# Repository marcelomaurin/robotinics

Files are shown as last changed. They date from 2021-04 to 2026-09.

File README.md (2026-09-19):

# Robotinics

[Português](README.md) · [English](README_EN.md) · [Español](README_ES.md)

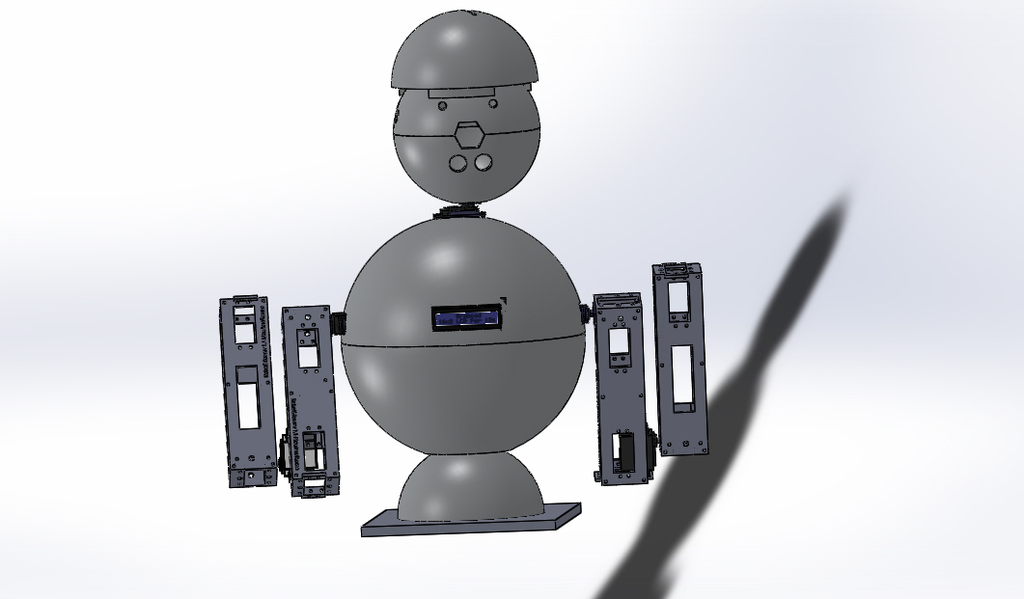
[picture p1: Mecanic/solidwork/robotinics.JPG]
Robotinics


Robotinics é uma plataforma aberta de robótica, automação e experimentação criada para integrar **mecânica, eletrônica, firmware, computação embarcada e software** em um mesmo projeto.

O objetivo não é oferecer apenas um robô pronto, mas uma base evolutiva para estudo, prototipagem e desenvolvimento de novas funcionalidades.

## Origem do projeto

O Robotinics nasceu em **2015** como **Trabalho de Conclusão de Curso (TCC)** do curso de **Técnico em Mecânica Industrial**, apresentado na **Etec José Martimiano da Silva**, em Ribeirão Preto/SP, unidade do **Centro Paula Souza**.

Esse contexto explica a natureza multidisciplinar do projeto desde sua origem: o trabalho não foi concebido apenas como software ou eletrônica, mas como um sistema integrado envolvendo **mecânica, fabricação de peças, eletrônica, acionamentos, sensores, microcontroladores e software**.

A partir do trabalho acadêmico original, o Robotinics continuou evoluindo como plataforma experimental, incorporando novas revisões mecânicas, placas eletrônicas, Arduino, Raspberry Pi, visão computacional e outros módulos de software.

Instituição: [Etec José Martimiano da Silva – Centro Paula Souza](https://www.cps.sp.gov.br/etecs/etec-jose-martimiano-da-silva/)

## Visão geral

O projeto reúne:

- estrutura mecânica e peças para fabricação e impressão 3D;
- projetos de placas eletrônicas e distribuição de alimentação;
- Arduino Mega como controlador principal de baixo nível;
- módulo de cabeça baseado em Arduino Nano;
- sensores, servomotores, motores, laser apontador e ultrassom;
- integração com Raspberry Pi;
- banco de dados e interface web;
- documentação didática e material histórico do projeto.

## Arquitetura

```text
                      Raspberry Pi
                 visão / software / lógica
                           │
                           │ serial
                           ▼
                     Arduino Mega
                controle físico principal
                  /        │         \
             motores    sensores    servos
                           │
                           ▼
                    MCabeca / Nano
                ┌──────────┼──────────┐
              Servo X    Servo Y    Ultrassom
                           │
                       Laser / LEDs
```

O Raspberry Pi fica responsável por processamento de mais alto nível. O Arduino Mega concentra a maior quantidade de I/O e executa o controle físico. O MCabeca é um módulo especializado da cabeça robótica.

## Módulos

| Módulo | Conteúdo |
|---|---|
| [Eletrônica](Eletronic/README.md) | esquemas, placas, alimentação e PCBs |
| [Mecânica](Mecanic/README.md) | SolidWorks, STL e peças estruturais |
| [Software](Software/README.md) | firmware, Raspberry, banco e interface |
| [Arduino](Software/arduino/README.md) | firmwares embarcados |
| [Mega](Software/arduino/robotinics/README.md) | controlador principal do robô |
| [MCabeca](Software/arduino/MCabeca/README.md) | cabeça ativa: servos, laser, LEDs e ultrassom |
| [Raspberry](Software/raspberry/README.md) | processamento de alto nível e I/O |
| [Robotinics AI](docs/ai/README.md) | TCHATGPT, internet, RAG, visão, agentes e documentação assistida |
| [Imagem Yocto](Software/raspberry/yocto/README.md) | Linux reproduzível para Raspberry Pi 4/5 |
| [Database](Software/database/README.md) | estrutura de dados do projeto |
| [Site](Software/site/README.md) | interface web histórica |
| [Documentação](docs/README.md) | manuais e material de referência |

## MCabeca e percepção ativa

O MCabeca possui dois servos associados a um **apontador laser**, LEDs e sensor ultrassônico. A intenção do módulo não é atuar como arma: o laser funciona como referência óptica e apontador visual.

Associado a uma câmera controlada pelo Raspberry Pi, o módulo pode ser usado para:

- apontamento visual;
- varredura angular;
- identificação do ponto laser na imagem;
- auxílio à estimativa de profundidade de uma câmera monocular;
- scanning de uma região;
- combinação de distância visual e ultrassônica;
- acompanhamento experimental de objetos.

A calibração visual pertence ao Raspberry Pi. O microcontrolador deve apenas receber e executar ângulos e comandos físicos.

## Continuação com IA no Raspberry Pi

A continuidade da Rev. 3 propõe o Raspberry Pi como **computador de bordo inteligente**, usando a biblioteca [TCHATGPT](https://github.com/marcelomaurin/CHATGPT) para integrar LLM, agentes, RAG, visão, voz e acesso controlado à internet.

A arquitetura preserva o princípio de segurança do projeto: a IA interpreta, pesquisa e planeja; o Arduino Mega continua responsável pelo controle físico determinístico.

Documentação: [docs/ai/README.md](docs/ai/README.md)

Para agentes de IA que precisem compreender ou atualizar este repositório, consulte também [AGENTS.md](AGENTS.md) e [AI_README.md](AI_README.md).

## Imagem Linux do Raspberry Pi

A continuidade do projeto possui uma camada Yocto própria em [Software/raspberry/yocto/README.md](Software/raspberry/yocto/README.md). Ela cria uma imagem reproduzível para Raspberry Pi 4/5 com gateway serial, rede, voz/visão opcionais e preparação para o runtime TCHATGPT ARM64.

## Firmware

O projeto possui dois firmwares principais:

### Arduino Mega

Local: [Software/arduino/robotinics](Software/arduino/robotinics)

Responsável por controle do robô, motores, servos, sensores, comunicação e segurança básica.

### Arduino Nano — MCabeca

Local: [Software/arduino/MCabeca](Software/arduino/MCabeca)

Responsável pelo módulo de cabeça robótica.

Os firmwares estão passando por uma modernização mantendo compatibilidade com o hardware e o protocolo legado:

- PR #3 — refatoração do firmware do Mega;
- PR #4 — otimização do MCabeca para Arduino Nano.

## Estrutura do repositório

```text
robotinics/
├── Eletronic/
│   ├── arduino/
│   ├── eagle/
│   ├── pcb/
│   └── pcb wizzard/
├── Mecanic/
│   ├── solidwork/
│   └── stl/
├── Software/
│   ├── arduino/
│   │   ├── robotinics/
│   │   └── MCabeca/
│   ├── database/
│   ├── raspberry/
│   │   └── yocto/
│   └── site/
└── docs/
```

## Robotinics Rev. 4

A evolução atual do projeto está organizada na [Robotinics Rev. 4](docs/rev4/README.md), que formaliza a arquitetura em camadas, o roadmap de modernização, a preservação do protocolo legado e os critérios de validação para firmware, Gateway, simulador, IA e distribuição.

A Rev. 4 é incremental: o hardware atual continua sendo a base do projeto e cada mudança estrutural deve ser validada antes de substituir comportamento existente.

## Documentação histórica

O repositório mantém o material completo produzido ao longo da evolução do projeto, inclusive o manual **Projetos IoT com Arduino e Raspberry**.

Consulte [docs/README.md](docs/README.md).

## Filosofia do projeto

Robotinics foi concebido como uma plataforma multidisciplinar. A evolução do projeto deve preservar quatro princípios:

1. hardware reproduzível;
2. módulos independentes;
3. protocolo compatível entre dispositivos;
4. separação entre controle físico e processamento de alto nível.

## Autor

**Marcelo Maurin Martins**

- GitHub: [marcelomaurin](https://github.com/marcelomaurin)
- Site: [Maurinsoft](https://maurinsoft.com.br)

---

Robotinics é um projeto experimental e educacional. Ao trabalhar com motores, alimentação elétrica, laser, baterias ou partes móveis, utilize procedimentos adequados de segurança.

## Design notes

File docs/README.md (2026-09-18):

# Documentação do Robotinics

[Projeto principal](../README.md) · [English](README.en.md) · [Español](README.es.md)

Esta pasta reúne documentação histórica e material didático relacionado ao Robotinics.

## Histórico e origem

O Robotinics foi apresentado originalmente em **2015** como **Trabalho de Conclusão de Curso (TCC)** do curso de **Técnico em Mecânica Industrial** da **Etec José Martimiano da Silva**, em Ribeirão Preto/SP, unidade do **Centro Paula Souza**.

O projeto surgiu com uma proposta multidisciplinar, reunindo mecânica, estrutura física, eletrônica, sensores, acionamentos, microcontroladores e software. O repositório atual preserva materiais de diferentes fases dessa evolução, incluindo arquivos mecânicos, placas, códigos, documentação didática e versões posteriores do sistema.

Instituição: [Etec José Martimiano da Silva – Centro Paula Souza](https://www.cps.sp.gov.br/etecs/etec-jose-martimiano-da-silva/)

## Documentação principal

A referência mais recente do projeto é a **Robotinics Rev. 3**, disponível em [rev3/README.md](rev3/README.md), com edições em português e inglês, manuscritos-fonte e arquivos de reconstrução.

A Rev. 3 consolida a arquitetura moderna do Robotinics, incluindo Raspberry Pi, TCHATGPT, agentes, visão, voz, RAG e controle supervisionado.

## Continuação de IA

A evolução posterior da arquitetura de IA está documentada em [ai/README.md](ai/README.md).

Essa documentação descreve a integração com internet, o runtime no Raspberry Pi e um agente específico para manter os READMEs sincronizados com o código.

## Material histórico

O repositório também preserva **Projetos IoT com Arduino e Raspberry** como documentação histórica.

Esse conteúdo registra conceitos, montagens, experimentos e etapas associadas ao desenvolvimento do projeto.

## Papel desta pasta

O objetivo de `docs/` é concentrar material que não pertence diretamente ao código-fonte ou aos arquivos de fabricação.

Exemplos de conteúdo adequado:

- manual de montagem;
- arquitetura;
- protocolo;
- pinagem;
- tutoriais;
- diagramas;
- histórico;
- imagens técnicas;
- procedimentos de teste.

## Organização futura sugerida

```text
docs/
├── architecture/
├── assembly/
├── electronics/
├── firmware/
├── protocol/
├── raspberry/
├── vision/
└── history/
```

## Documentação modular

A documentação atual está sendo distribuída também em READMEs próximos aos respectivos módulos.

Isso facilita a navegação:

- eletrônica documentada em `Eletronic/`;
- mecânica em `Mecanic/`;
- software em `Software/`;
- Mega e MCabeca em suas próprias pastas.

A pasta `docs/` deve concentrar materiais mais extensos e transversais ao projeto.

## Idiomas

A documentação principal utiliza:

- Português;
- English;
- Español.

A versão em português é usada como referência principal quando não houver outra indicação.

## Pinout dos controladores

A documentação de pinout dos controladores está em [hardware/pinout/README.md](hardware/pinout/README.md), cobrindo Arduino Mega/ATmega2560, MCabeca/ATmega328P e Raspberry Pi 4/5.

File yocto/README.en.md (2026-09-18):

# Robotinics Yocto Image

[Português](README.md) · [Español](README.es.md)

This directory defines the reproducible Robotinics Raspberry Pi image using Yocto Project 6.0 Wrynose LTS, meta-raspberrypi and the custom meta-robotinics layer.

Default machine is raspberrypi4-64, with raspberrypi5 also supported by the manifests.

Build:

    cd yocto
    ./scripts/build.sh rpi4

The image includes networking, SSH, Python, serial gateway support, optional vision and speech features, and the filesystem/configuration foundation for the TCHATGPT ARM64 runtime.

The TCHATGPT source recipe is pinned for reproducibility but is not installed by default until ARM64 compilation is validated.

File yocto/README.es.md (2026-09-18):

# Imagen Yocto de Robotinics

[Português](README.md) · [English](README.en.md)

Esta carpeta define la imagen reproducible para Raspberry Pi usando Yocto Project 6.0 Wrynose LTS, meta-raspberrypi y la capa meta-robotinics.

La máquina predeterminada es raspberrypi4-64 y también existe un manifiesto para raspberrypi5.

Build:

    cd yocto
    ./scripts/build.sh rpi4

La imagen incluye red, SSH, Python, gateway serie, funciones opcionales de visión y voz, y la base para el runtime TCHATGPT ARM64.

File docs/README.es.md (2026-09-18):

# Documentación de Robotinics

[Proyecto principal](../README_ES.md) · [Português](README.md) · [English](README.en.md)

Esta carpeta contiene documentación histórica y material educativo.

## Historia y origen

Robotinics fue presentado originalmente en **2015** como **Trabajo de Conclusión de Curso (TCC)** del curso de **Técnico en Mecánica Industrial** de la **Etec José Martimiano da Silva**, en Ribeirão Preto, São Paulo, Brasil, unidad del **Centro Paula Souza**.

El proyecto tuvo un carácter multidisciplinario desde su origen, integrando mecánica, estructura física, electrónica, sensores, accionamientos, microcontroladores y software. El repositorio actual conserva materiales de diferentes etapas de esa evolución.

Institución: [Etec José Martimiano da Silva – Centro Paula Souza](https://www.cps.sp.gov.br/etecs/etec-jose-martimiano-da-silva/)

Uno de los principales recursos es el material **Proyectos IoT con Arduino y Raspberry**.

La documentación específica se mantiene cerca de cada módulo. `docs/` debe concentrar arquitectura, montaje, protocolos, diagramas, tutoriales e historia del proyecto.

Los idiomas principales son portugués, inglés y español.

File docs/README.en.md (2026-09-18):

# Robotinics Documentation

[Main project](../README_EN.md) · [Português](README.md) · [Español](README.es.md)

This folder contains historical documentation and educational material related to Robotinics.

## History and origin

Robotinics was originally presented in **2015** as a **final course project (TCC)** for the **Industrial Mechanics Technical Program** at **Etec José Martimiano da Silva**, Ribeirão Preto, São Paulo, Brazil, part of **Centro Paula Souza**.

The project was multidisciplinary from the start, combining mechanics, physical structure, electronics, sensors, actuators, microcontrollers and software. The current repository preserves material from different stages of that evolution.

Institution: [Etec José Martimiano da Silva – Centro Paula Souza](https://www.cps.sp.gov.br/etecs/etec-jose-martimiano-da-silva/)

A major resource is the **IoT Projects with Arduino and Raspberry** material stored in the repository.

Module-specific documentation is kept near each subsystem, while `docs/` should contain broader material such as architecture, assembly guides, protocol specifications, diagrams, tutorials and project history.

Primary documentation languages are Portuguese, English and Spanish.

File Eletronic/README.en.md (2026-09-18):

# Robotinics Electronics

[Main project](../README_EN.md) · [Português](README.md) · [Español](README.es.md)

This directory contains the electronic layer of Robotinics. It connects the embedded controllers to motors, servos, sensors, LEDs, auxiliary modules and power circuitry.

## Purpose

The electronics were designed to keep the robot modifiable and repairable without depending on one proprietary board. The repository contains several generations of circuit files, serving both as fabrication references and as a historical record of the project.

## Structure

### `arduino/`

Pinout notes and controller connection references.

### `eagle/`

Autodesk EAGLE projects, including:

- servo controller board;
- LED board;
- charger circuit;
- 5 V distribution board.

### `pcb/`

PCB layouts, fabrication mirrors and images from multiple revisions.

### `pcb wizzard/`

Historical PCB Wizard files.

## Software integration

Electronic pin assignments must match the embedded firmware:

- Arduino Mega: main physical controller;
- Arduino Nano / MCabeca: specialized head module.

Any pinout change should be reflected in hardware, firmware and documentation at the same time.

## Power

Motors and servos can require substantially more current than Arduino regulators can safely provide. When reproducing the hardware:

- size the power supply correctly;
- use common ground where required;
- avoid powering multiple servos from the Arduino regulator;
- provide appropriate protection and distribution;
- verify voltage drop under simultaneous load.

## Repository status

This folder contains historical and current material. Not every file should be treated as production-ready.

The documentation effort should progressively identify the official reference schematic, PCB, BOM and pinout.

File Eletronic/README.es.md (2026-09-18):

# Electrónica de Robotinics

[Proyecto principal](../README_ES.md) · [Português](README.md) · [English](README.en.md)

Este directorio contiene la capa electrónica de Robotinics. Conecta los controladores embebidos con motores, servos, sensores, LEDs, módulos auxiliares y circuitos de alimentación.

## Objetivo

La electrónica fue concebida para permitir que el robot sea modificable y reparable sin depender de una placa propietaria única. El repositorio contiene varias generaciones de archivos, útiles como referencia de fabricación y como registro histórico.

## Estructura

### `arduino/`

Notas de pines y conexiones.

### `eagle/`

Proyectos EAGLE, incluyendo:

- control de servomotores;
- placas de LEDs;
- cargador;
- distribución de 5 V.

### `pcb/`

Diseños PCB, espejos e imágenes de distintas revisiones.

### `pcb wizzard/`

Archivos históricos de PCB Wizard.

## Integración

Los pines deben coincidir con los firmwares:

- Arduino Mega: controlador físico principal;
- Arduino Nano / MCabeca: módulo de cabeza.

Todo cambio de pin debe reflejarse en hardware, firmware y documentación.

## Alimentación

Los motores y servos pueden requerir corrientes elevadas. Se recomienda dimensionar correctamente la fuente, utilizar masa común cuando corresponda, evitar alimentar múltiples servos desde el regulador del Arduino y verificar caída de tensión bajo carga.

## Estado del material

Existen archivos de diferentes generaciones. No todos representan una versión lista para producción.

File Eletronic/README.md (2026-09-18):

# Eletrônica do Robotinics

[Projeto principal](../README.md) · [English](README.en.md) · [Español](README.es.md)

Este diretório concentra a parte eletrônica do Robotinics. Ele representa a camada que conecta os controladores embarcados aos motores, servomotores, sensores, LEDs, módulos auxiliares e circuitos de alimentação.

## Objetivo

A proposta da eletrônica do Robotinics é permitir que o robô seja construído, modificado e reparado sem depender de uma única placa proprietária. O projeto reúne arquivos de diferentes períodos de evolução, servindo tanto como base de fabricação quanto como registro histórico das soluções adotadas.

## Estrutura

### `arduino/`

Contém anotações de pinagem e referências de conexão relacionadas aos microcontroladores.

O arquivo `pinos arduino.txt` registra parte da distribuição física usada no Arduino Mega, incluindo conexões de servos, motores, RF e LCD.

### `eagle/`

Contém projetos criados no Autodesk EAGLE.

Entre os circuitos existentes estão:

- placa controladora de servomotor;
- placa de LEDs;
- circuito do carregador;
- placa de distribuição de 5 V.

Esses arquivos devem ser tratados como projetos de hardware sujeitos a revisão. Antes de fabricar uma placa, confirme esquemático, alimentação, versão dos componentes e correspondência com o firmware utilizado.

### `pcb/`

Contém arquivos de placa, espelhos de fabricação e imagens de diferentes revisões.

Há materiais para:

- controle de servomotores;
- controle de LEDs;
- distribuição elétrica;
- fonte;
- versões intermediárias e históricas das placas.

### `pcb wizzard/`

Contém arquivos produzidos em versões anteriores do projeto usando PCB Wizard.

## Integração com o software

A eletrônica deve acompanhar a pinagem dos firmwares:

- Arduino Mega: controlador físico principal;
- Arduino Nano / MCabeca: módulo especializado da cabeça.

Alterações de pinagem devem ser refletidas simultaneamente no hardware, no firmware e na documentação.

## Alimentação

Motores e servos podem exigir correntes significativamente maiores do que as fornecidas diretamente pelos reguladores dos microcontroladores.

Ao reproduzir ou modificar o circuito:

- dimensione corretamente a fonte;
- mantenha terra comum entre os módulos quando necessário;
- evite alimentar vários servos diretamente pelo regulador do Arduino;
- utilize proteção e distribuição adequadas;
- verifique queda de tensão durante acionamentos simultâneos.

## Situação do conteúdo

O diretório contém material de diferentes gerações do Robotinics. Nem todo arquivo representa a revisão mais recente ou uma placa pronta para produção.

O objetivo da modernização da documentação é permitir identificar progressivamente:

1. arquivos históricos;
2. versão de referência;
3. esquemático atual;
4. PCB atual;
5. lista de materiais;
6. pinagem oficial.

## Segurança

Antes de energizar qualquer circuito, confirme polaridade, tensão nominal, corrente e isolamento. Motores, baterias e servos podem provocar aquecimento, curto-circuito ou movimento inesperado quando ligados incorretamente.

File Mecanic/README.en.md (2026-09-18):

# Robotinics Mechanics

[Main project](../README_EN.md) · [Português](README.md) · [Español](README.es.md)

The `Mecanic` directory contains the physical Robotinics structure: CAD models, assemblies and parts for 3D printing.

## Purpose

Mechanical design is part of the system architecture. Robotinics was built so software, electronics and physical structure can evolve together.

## Structure

### `solidwork/`

SolidWorks parts and assemblies, including body sections, bases, arms, head parts, laser support and Raspberry Pi support.

### `stl/`

Exported files for fabrication and 3D printing.

## Head module

The mechanical head supports two servo axes, the laser pointer and the ultrasonic sensor. It can work together with a camera handled by the Raspberry Pi.

The laser is an optical/visual reference used in active-perception and scanning experiments.

## Revisions

Several historical revisions coexist. Before printing, verify scale, mounting points, servo compatibility and the intended assembly revision.

A future reference release should provide a complete mechanical BOM, printing orientation, material recommendations and assembly sequence.

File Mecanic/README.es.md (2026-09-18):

# Mecánica de Robotinics

[Proyecto principal](../README_ES.md) · [Português](README.md) · [English](README.en.md)

La carpeta `Mecanic` contiene la estructura física de Robotinics: modelos CAD, ensamblajes y piezas para impresión 3D.

## Estructura

### `solidwork/`

Piezas y ensamblajes SolidWorks.

### `stl/`

Archivos exportados para fabricación e impresión 3D.

## Módulo de cabeza

La cabeza soporta dos ejes con servos, el puntero láser y el sensor ultrasónico. Puede trabajar junto con una cámara procesada por Raspberry Pi.

El láser funciona como referencia visual/óptica para experimentos de percepción activa.

## Revisiones

Coexisten varias revisiones históricas. Antes de imprimir una pieza, verifique escala, fijaciones, compatibilidad con servos y versión de montaje.

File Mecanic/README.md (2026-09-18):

# Mecânica do Robotinics

[Projeto principal](../README.md) · [English](README.en.md) · [Español](README.es.md)

A pasta `Mecanic` reúne a estrutura física do Robotinics: modelos CAD, montagens e peças destinadas à impressão 3D.

## Objetivo

A mecânica faz parte da arquitetura do projeto. O Robotinics foi concebido para que software, eletrônica e estrutura física possam evoluir em conjunto.

O repositório não contém apenas uma carcaça: ele inclui peças funcionais relacionadas a braços, corpo, cabeça, suportes e integração dos componentes eletrônicos.

## Estrutura

### `solidwork/`

Contém arquivos de peças e montagens em SolidWorks.

Entre os arquivos existentes estão:

- montagem completa do Robotinics;
- corpo;
- bases;
- braços;
- suporte do laser;
- suporte do Raspberry Pi;
- peças de cabeça;
- extensões e suportes auxiliares.

Também existem imagens de referência da montagem.

### `stl/`

Contém arquivos exportados para impressão 3D.

Entre as peças disponíveis estão:

- base do braço;
- extensão do braço;
- corpo inferior e superior;
- placa da cabeça;
- partes inferior e superior da cabeça;
- prolongadores;
- suporte do laser;
- suporte do Raspberry Pi.

## Cabeça e laser

A estrutura da cabeça foi projetada para acomodar o módulo MCabeca.

O conjunto possui:

- dois eixos de movimento por servo;
- suporte para apontador laser;
- integração com sensor ultrassônico;
- possibilidade de trabalhar junto a uma câmera.

O apontador laser é utilizado como referência visual/óptica. Associado à câmera e ao processamento no Raspberry Pi, pode apoiar experimentos de scanning e percepção ativa.

## Revisões

O diretório contém peças de diferentes revisões.

Antes de imprimir:

1. confirme o nome e a revisão da peça;
2. valide a escala do STL;
3. verifique pontos de fixação;
4. confirme compatibilidade com servos e placas instalados;
5. confira a montagem completa antes de fabricar várias unidades.

## Próxima evolução documental

Uma revisão futura deve identificar claramente:

- conjunto mecânico de referência;
- lista completa das peças;
- quantidade necessária de cada peça;
- orientação de impressão;
- material recomendado;
- parafusos e elementos de fixação;
- sequência de montagem.

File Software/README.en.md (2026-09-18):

# Robotinics Software

[Main project](../README_EN.md) · [Português](README.md) · [Español](README.es.md)

This directory contains the software layers of Robotinics.

## Architecture

```text
Raspberry Pi
  processing / integration / vision
                │
                ▼
          Arduino Mega
       main physical controller
          │           │
          │           └── MCabeca / Arduino Nano
          │
          ├── motors
          ├── servos
          └── sensors
```

## Modules

- [Arduino](arduino/README.md): embedded firmware;
- [Raspberry](raspberry/README.md): high-level processing and integration;
- [Database](database/README.md): project data structures;
- [Site](site/README.md): historical web interface.

## Design principle

Microcontrollers should remain deterministic and hardware-focused. Vision, camera calibration, triangulation, mission logic and AI belong to the Raspberry Pi or another high-level computer.

Protocol compatibility between devices is considered part of the Robotinics system contract.

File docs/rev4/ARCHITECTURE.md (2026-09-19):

# Arquitetura Robotinics Rev. 4

## Visão geral

A Rev. 4 formaliza a separação entre hardware, controle determinístico e processamento de alto nível.

```text
Usuário / Control Center / serviços
              |
              v
       Robotinics AI Runtime
      tarefas / RAG / visão / voz
              |
              v
       Robotinics Gateway
   validação / fila / estado / API
              |
              v
         Arduino Mega
        Body Controller
       /      |       \
 motores   sensores   servos
              |
              +-------------------+
                                  |
                                  v
                         Arduino Nano
                         Head Controller
                      pan / tilt / laser
                       LEDs / ultrassom
```

## Nível 0 — Hardware

Inclui atuadores, sensores, drivers, alimentação, estrutura mecânica, placas e cabeamento.

Responsabilidades:
- executar o efeito físico;
- oferecer sinais elétricos aos controladores;
- respeitar limites mecânicos e elétricos definidos pelo projeto.

## Nível 1 — Controle determinístico

### Body Controller — Arduino Mega

Responsabilidades:
- motores de locomoção;
- servos do corpo;
- sensores diretamente conectados;
- comandos Device;
- intertravamentos simples;
- parada segura;
- comunicação com o computador de bordo;
- encaminhamento de comandos para módulos subordinados quando necessário.

Não é responsabilidade do Mega:
- interpretação de linguagem natural;
- acesso à internet;
- planejamento por LLM;
- visão computacional de alto nível.

### Head Controller — Arduino Nano / MCabeca

Responsabilidades:
- pan/tilt;
- laser apontador;
- LEDs;
- olhos;
- ultrassom;
- varreduras físicas locais.

O Raspberry é responsável por calibração visual e interpretação de imagem.

## Nível 2 — Cognitive Controller — Raspberry Pi

### Gateway

Único serviço autorizado a conversar diretamente com o Body Controller pela serial principal.

Responsabilidades:
- abrir e manter a conexão;
- serializar comandos;
- aplicar catálogo/validação;
- timeout;
- request id;
- parser de respostas;
- estado atual;
- histórico;
- eventos;
- health check.

### AI Runtime

Responsabilidades:
- receber perguntas;
- criar tarefas;
- consultar telemetria;
- consultar documentação;
- RAG;
- visão;
- voz;
- internet controlada;
- produzir diagnóstico e propostas de ação.

A saída do LLM não é autorização para hardware.

## Fluxo de ação física

```text
pedido do usuário
      |
      v
interpretação
      |
      v
plano / proposta
      |
      v
política e validação
      |
      v
confirmação quando necessária
      |
      v
Gateway
      |
      v
Body/Head Controller
      |
      v
hardware
      |
      v
telemetria observada
```

## Estado e telemetria

O estado deve distinguir:

- estado solicitado;
- estado confirmado pelo controlador;
- telemetria observada;
- inferência da IA.

Nunca tratar intenção de comando como comprovação de execução.

## Segurança

A segurança física deve existir abaixo da camada de IA.

Requisitos de arquitetura:
- parada prioritária;
- timeout de movimento;
- watchdog;
- limites de servo;
- rejeição de comandos desconhecidos;
- modo degradado quando o Raspberry falhar;
- ausência de execução direta de conteúdo vindo da internet.

## Interfaces futuras

A arquitetura deve permitir, sem obrigar a substituição do hardware atual:

- outros controladores;
- novos módulos de sensores;
- câmeras;
- microfones;
- alto-falantes;
- novos transportes além da serial;
- clientes web, desktop ou mobile.

A descoberta de capacidades deve reduzir dependência de configuração rígida, mas sem remover suporte ao protocolo legado.

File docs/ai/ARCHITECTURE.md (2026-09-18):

# Arquitetura de IA do Robotinics

## Princípio

A IA é uma camada cognitiva, não uma camada elétrica. Ela pode interpretar intenção, buscar informação, montar planos e explicar resultados. O firmware continua responsável pelo comportamento determinístico.

## Camadas

### 1. Hardware

Motores, sensores, servos, laser, LEDs e alimentação.

### 2. Controle determinístico

Arduino Mega e MCabeca.

Responsabilidades:

- comandos físicos;
- limites;
- timeouts;
- estados;
- intertravamentos;
- leituras.

### 3. Robot Gateway

Executado no Raspberry.

Responsável por:

- serial;
- catálogo de comandos;
- normalização de telemetria;
- timeout;
- heartbeat;
- request_id;
- log de execução.

### 4. Serviços

- câmera;
- voz;
- RAG;
- internet;
- banco;
- arquivos;
- telemetria.

### 5. TCHATGPT

- LLM;
- agente;
- planejamento;
- seleção de ferramenta;
- explicação;
- contexto.

## Internet como ferramenta

A internet é uma ferramenta do agente, equivalente a câmera ou RAG.

O LLM não recebe acesso irrestrito ao sistema operacional.

A ferramenta de internet recebe uma solicitação estruturada e retorna fontes, data de consulta, título e resumo.

## Estado central

O Raspberry deve manter um `RobotState` independente da conversa:

```text
connection
mode
armed
battery
motors
servos
distances
head_position
laser
leds
last_telemetry
faults
current_task
```

## Tarefas

Toda pergunta pode gerar uma tarefa lógica:

```text
Task
├── understand
├── collect_context
├── collect_telemetry
├── search_rag
├── search_internet
├── reason
└── answer
```

Ações físicas acrescentam:

```text
├── build_action_plan
├── validate
├── request_confirmation
├── execute
└── verify_telemetry
```

## Segurança

O validador deve rejeitar:

- comando não catalogado;
- parâmetro fora de faixa;
- movimento em estado não armado;
- telemetria antiga;
- ação baseada apenas em conteúdo web;
- cadeia ilimitada de ações;
- repetição automática após falha;
- ação física baseada apenas em memória de conversa.

## Operação sem internet

O robô deve continuar controlável sem internet e sem LLM.

Sem internet:

- RAG local continua disponível;
- telemetria continua disponível;
- controle manual continua disponível;
- segurança continua funcionando.

Sem LLM:

- gateway e firmware continuam operacionais.

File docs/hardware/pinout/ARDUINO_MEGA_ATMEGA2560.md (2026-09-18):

# Arduino Mega 2560 / ATmega2560 — Pinout Robotinics

[Índice](README.md) · [Firmware](../../../Software/arduino/robotinics/README.md)

O Arduino Mega 2560 é o controlador físico principal do Robotinics.

## Interfaces principais

| Recurso | Pinos Arduino Mega | Porta ATmega2560 | Uso Robotinics |
|---|---|---|---|
| Serial0 | D0 RX / D1 TX | PE0 / PE1 | USB/console, 115200 bps |
| Serial1 | D19 RX1 / D18 TX1 | PD2 / PD3 | Bluetooth, 9600 bps |
| Serial2 | D17 RX2 / D16 TX2 | PH0 / PH1 | reservado/associado historicamente a RF |
| Serial3 | D15 RX3 / D14 TX3 | PJ0 / PJ1 | GPS, 4800 bps |
| I²C | D20 SDA / D21 SCL | PD1 / PD0 | LCD I²C, endereço 0x20 |
| SPI | D50–D53 | PB3/PB2/PB1/PB0 | disponível; sem uso principal confirmado |

## Servomotores

| Função Robotinics | Pino Mega | ATmega2560 | Recurso |
|---|---:|---|---|
| Cabeça principal | D6 | PH3 | PWM |
| Braço direito | D44 | PL5 | PWM |
| Movimento/punho direito | D8 | PH5 | PWM |
| Braço esquerdo | D9 | PH6 | PWM |
| Garra esquerda | D10 | PB4 | PWM |
| Garra direita | D11 | PB5 | PWM |
| Punho esquerdo | D46 | PL3 | PWM |

Observação: a biblioteca `Servo` usa temporizadores internos e não depende exclusivamente do PWM de hardware do pino.

## Ponte H / tração

| Sinal | Pino Mega | ATmega2560 | Função |
|---|---:|---|---|
| ENA | D26 | PA4 | habilitação motor A |
| IN1 | D28 | PA6 | direção motor A |
| IN2 | D30 | PC7 | direção motor A |
| IN3 | D34 | PC3 | direção motor B |
| IN4 | D32 | PC5 | direção motor B |
| ENB | D36 | PC1 | habilitação motor B |

## Ultrassônicos

| Sensor | Trigger | MCU Trigger | Echo | MCU Echo |
|---|---:|---|---:|---|
| Ré | D2 | PE4 | D3 | PE5 |
| Frente | D40 | PG1 | D35 | PC2 |
| Cabeça/corpo | D41 | PG0 | D42 | PL7 |

## Entradas analógicas

| Função | Arduino | ATmega2560 |
|---|---|---|
| Corrente | A0 | PF0 / ADC0 |
| Acelerômetro X | A1 | PF1 / ADC1 |
| Acelerômetro Y | A2 | PF2 / ADC2 |
| Acelerômetro Z | A3 | PF3 / ADC3 |
| Sensor de gás | A4 | PF4 / ADC4 |
| Canal adicional gás | A5 | PF5 / ADC5 |
| Tensão | A6 | PF6 / ADC6 |

## Comunicação com controlador secundário

O firmware declara `SoftwareSerial mySerial(Arduino2TX, Arduino2RX)` com `Arduino2TX=38` e `Arduino2RX=37`. No construtor SoftwareSerial a ordem é receivePin, transmitPin.

| Papel real | Pino Mega | ATmega2560 |
|---|---:|---|
| RX SoftwareSerial | D38 | PD7 |
| TX SoftwareSerial | D37 | PC0 |

Os nomes históricos das constantes estão invertidos em relação à semântica do construtor. Não alterar a fiação apenas pelo nome da constante.

## Rádio frequência

| Sinal | Pino Mega | MCU |
|---|---:|---|
| RF RX | D17 | PH0 / RX2 |
| RF TX | D16 | PH1 / TX2 |

## Pinout digital completo do Mega

| Arduino | ATmega2560 | Arduino | ATmega2560 |
|---:|---|---:|---|
| D0 | PE0 | D27 | PA5 |
| D1 | PE1 | D28 | PA6 |
| D2 | PE4 | D29 | PA7 |
| D3 | PE5 | D30 | PC7 |
| D4 | PG5 | D31 | PC6 |
| D5 | PE3 | D32 | PC5 |
| D6 | PH3 | D33 | PC4 |
| D7 | PH4 | D34 | PC3 |
| D8 | PH5 | D35 | PC2 |
| D9 | PH6 | D36 | PC1 |
| D10 | PB4 | D37 | PC0 |
| D11 | PB5 | D38 | PD7 |
| D12 | PB6 | D39 | PG2 |
| D13 | PB7 | D40 | PG1 |
| D14 | PJ1 | D41 | PG0 |
| D15 | PJ0 | D42 | PL7 |
| D16 | PH1 | D43 | PL6 |
| D17 | PH0 | D44 | PL5 |
| D18 | PD3 | D45 | PL4 |
| D19 | PD2 | D46 | PL3 |
| D20 | PD1 | D47 | PL2 |
| D21 | PD0 | D48 | PL1 |
| D22 | PA0 | D49 | PL0 |
| D23 | PA1 | D50 | PB3 |
| D24 | PA2 | D51 | PB2 |
| D25 | PA3 | D52 | PB1 |
| D26 | PA4 | D53 | PB0 |

## Entradas analógicas completas

| Arduino | MCU | Arduino | MCU |
|---:|---|---:|---|
| A0 | PF0 | A8 | PK0 |
| A1 | PF1 | A9 | PK1 |
| A2 | PF2 | A10 | PK2 |
| A3 | PF3 | A11 | PK3 |
| A4 | PF4 | A12 | PK4 |
| A5 | PF5 | A13 | PK5 |
| A6 | PF6 | A14 | PK6 |
| A7 | PF7 | A15 | PK7 |

## Alimentação

Motores e servos não devem ser alimentados diretamente pelos pinos de I/O do ATmega2560. Documentar separadamente fonte de lógica, fonte de servos, fonte dos motores, reguladores, aterramento comum e proteções.

## Diagrama visual

Pinout funcional do Arduino Mega no Robotinics

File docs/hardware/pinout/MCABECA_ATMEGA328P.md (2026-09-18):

# MCabeca — Arduino Nano / ATmega328P

[Índice](README.md) · [MCabeca](../../../Software/arduino/MCabeca/README.md)

O MCabeca utiliza Arduino Nano / ATmega328P para controlar a cabeça física do Robotinics.

## Pinagem usada

| Função | Nano | ATmega328P | Recurso |
|---|---:|---|---|
| Echo ultrassônico | D2 | PD2 | INT0 |
| Laser | D3 | PD3 | PWM / INT1 |
| LED vermelho | D4 | PD4 | digital |
| LED azul | D6 | PD6 | PWM |
| Olhos | D7 | PD7 | digital |
| Servo X | D8 | PB0 | digital |
| LED verde | D9 | PB1 | PWM |
| Servo Y | D12 | PB4 | digital |
| Trigger ultrassônico | D13 | PB5 | SCK / LED onboard |

## UART

| Função | Nano | ATmega328P |
|---|---:|---|
| RX | D0 | PD0 / RXD |
| TX | D1 | PD1 / TXD |

No firmware histórico atualmente em `master`, a UART é inicializada em 57600 bps. Qualquer alteração de velocidade precisa ser feita nos dois lados da comunicação.

## Servo X/Y

- Servo X → D8 / PB0
- Servo Y → D12 / PB4

O Nano recebe ângulos; calibração de câmera e conversão pixel→ângulo pertencem ao Raspberry Pi.

## Laser

Laser → D3 / PD3. O laser é apontador/referência óptica. Se o módulo exigir corrente acima do permitido pelo I/O, usar transistor/MOSFET adequado.

## LEDs

- Vermelho → D4 / PD4
- Azul → D6 / PD6
- Verde → D9 / PB1
- Olhos → D7 / PD7

## Ultrassom

- Trigger → D13 / PB5
- Echo → D2 / PD2

## Pinout lógico do Nano

| Nano | ATmega328P | Observação |
|---:|---|---|
| D0 | PD0 | RX |
| D1 | PD1 | TX |
| D2 | PD2 | INT0 |
| D3 | PD3 | PWM / INT1 |
| D4 | PD4 | digital |
| D5 | PD5 | PWM |
| D6 | PD6 | PWM |
| D7 | PD7 | digital |
| D8 | PB0 | digital |
| D9 | PB1 | PWM |
| D10 | PB2 | PWM / SS |
| D11 | PB3 | PWM / MOSI |
| D12 | PB4 | MISO |
| D13 | PB5 | SCK |
| A0 | PC0 | ADC0 |
| A1 | PC1 | ADC1 |
| A2 | PC2 | ADC2 |
| A3 | PC3 | ADC3 |
| A4 | PC4 | ADC4 / SDA |
| A5 | PC5 | ADC5 / SCL |
| A6 | ADC6 | somente analógico |
| A7 | ADC7 | somente analógico |

## Alimentação

O Nano e os periféricos devem compartilhar referência de GND. Servos devem ter alimentação dimensionada adequadamente e não devem depender do regulador do Nano.

## Diagrama visual

Pinout funcional do MCabeca / Arduino Nano

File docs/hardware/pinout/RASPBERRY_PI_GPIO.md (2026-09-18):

# Raspberry Pi 4/5 — GPIO de 40 pinos

[Índice](README.md) · [Raspberry Pi](../../../Software/raspberry/README.md)

O Raspberry Pi é o computador de bordo do Robotinics. O SoC Broadcom é BGA; para montagem/manutenção o pinout relevante é o header GPIO de 40 pinos.

## Header

| Physical | Função | Physical | Função |
|---:|---|---:|---|
| 1 | 3.3 V | 2 | 5 V |
| 3 | GPIO2 / SDA1 | 4 | 5 V |
| 5 | GPIO3 / SCL1 | 6 | GND |
| 7 | GPIO4 | 8 | GPIO14 / TXD0 |
| 9 | GND | 10 | GPIO15 / RXD0 |
| 11 | GPIO17 | 12 | GPIO18 / PWM0 |
| 13 | GPIO27 | 14 | GND |
| 15 | GPIO22 | 16 | GPIO23 |
| 17 | 3.3 V | 18 | GPIO24 |
| 19 | GPIO10 / MOSI | 20 | GND |
| 21 | GPIO9 / MISO | 22 | GPIO25 |
| 23 | GPIO11 / SCLK | 24 | GPIO8 / CE0 |
| 25 | GND | 26 | GPIO7 / CE1 |
| 27 | GPIO0 / ID_SD | 28 | GPIO1 / ID_SC |
| 29 | GPIO5 | 30 | GND |
| 31 | GPIO6 | 32 | GPIO12 / PWM0 |
| 33 | GPIO13 / PWM1 | 34 | GND |
| 35 | GPIO19 / PWM1 / PCM_FS | 36 | GPIO16 |
| 37 | GPIO26 | 38 | GPIO20 / PCM_DIN |
| 39 | GND | 40 | GPIO21 / PCM_DOUT |

## Uso atual no Robotinics

A arquitetura moderna prevê Raspberry Pi ↔ Arduino Mega por USB serial: Raspberry USB → `/dev/ttyACM0` → USB/Serial0 do Mega.

Portanto GPIO14/GPIO15 não são necessários para a comunicação principal.

## UART GPIO futura

- Physical 8 = GPIO14 / TXD0
- Physical 10 = GPIO15 / RXD0
- Physical 6 = GND

### Atenção

O Raspberry Pi usa lógica de 3,3 V. O Arduino Mega usa tipicamente 5 V. Nunca conecte diretamente uma saída de 5 V do Mega a um GPIO do Raspberry. Use conversor de nível apropriado.

## I²C

- Physical 3 = GPIO2 / SDA1
- Physical 5 = GPIO3 / SCL1

## SPI

- Physical 19 = GPIO10 / MOSI
- Physical 21 = GPIO9 / MISO
- Physical 23 = GPIO11 / SCLK
- Physical 24 = GPIO8 / CE0
- Physical 26 = GPIO7 / CE1

## Alimentação

Os pinos 5 V e 3,3 V são alimentação, não GPIO. Nunca aplique 5 V em um GPIO BCM.

## Raspberry Pi 4 e 5

Para os sinais GPIO tradicionais documentados aqui, o header físico de 40 pinos mantém compatibilidade. Funções alternativas específicas do SoC devem ser confirmadas antes do uso.

## Diagrama de conexão com o Mega

Raspberry Pi conectado ao Arduino Mega

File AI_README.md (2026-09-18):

# Robotinics — Entrada rápida para IA

Este arquivo fornece contexto rápido a um agente de IA antes de modificar o projeto.

## O que é o Robotinics

Robotinics é uma plataforma robótica multidisciplinar iniciada em 2015 como TCC de Técnico em Mecânica Industrial e posteriormente expandida com Arduino, Raspberry Pi, software, visão e IA.

## Arquitetura

- Raspberry Pi: processamento de alto nível;
- Arduino Mega: controle físico principal;
- Arduino Nano / MCabeca: cabeça robótica;
- TCHATGPT: camada de IA da Rev. 3 e continuidade atual;
- internet: ferramenta consultiva controlada pelo Raspberry;
- RAG: documentação local do próprio projeto.

## Regra principal

**IA sugere, interpreta, pesquisa e planeja. O controle físico é validado e executado por camadas determinísticas.**

## Antes de alterar qualquer coisa

Leia `AGENTS.md`.

Depois leia o README do módulo afetado e, quando relevante, `docs/rev3/`.

## Continuação de IA

A proposta atual está em `docs/ai/` e `Software/raspberry/AI/`.

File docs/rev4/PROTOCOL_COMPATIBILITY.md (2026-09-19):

# Robotinics Device Protocol 1.x

## Status

Esta especificação descreve o protocolo textual compatível com o firmware histórico do Robotinics e suas extensões compatíveis da Rev. 4.

O objetivo é permitir que um cliente implemente integração com o Body Controller sem precisar ler o firmware.

## Transporte

### Body Controller / Arduino Mega

Canal principal atual:

```text
USB Serial
115200 bps
8N1
linha terminada por LF
```

Bluetooth legado:

```text
9600 bps
linha terminada por LF
```

Canal para MCabeca:

```text
9600 bps
```

## Modelo de requisição

Cada comando é enviado como uma única linha:

```text
COMMAND\n
```

O Body Controller pode emitir zero ou mais linhas de resposta e termina o processamento do comando com:

```text
$>
```

O Gateway usa esse prompt como marcador de conclusão da requisição.

## Compatibilidade

Protocol 1.x preserva:

- nomes dos comandos históricos;
- semântica dos comandos;
- formato textual;
- prompt `$>`;
- baud rates existentes;
- namespace `MCAB:`.

Extensões 1.x podem adicionar novos comandos e novas linhas estruturadas, desde que clientes antigos continuem funcionando.

## Categorias de comandos

### Movimento

```text
FRENTE
RE
PARA
GESQ
GDIR
```

`PARA` possui prioridade lógica no parser.

Movimento contínuo é protegido por SafetyController:

- watchdog de controle;
- timeout máximo de ordem;
- parada por obstáculo.

### Sensores

```text
ULTRA
ULTRA1
ULTRA2
ACEL
GAS
CORR
GPS
```

### Servos do corpo

```text
GCABECAESQ=<0..180>
GCABECADIR=<0..180>
GBDIR=<0..180>
GBESQ=<0..180>
GPGARRADIR=<0..180>
GPGARRAESQ=<0..180>
GPPUNHOESQ=<0..180>
GPPUNHODIR=<0..180>
```

O Gateway valida a faixa 0..180 antes de encaminhar.

### Interface local

```text
CLS
LCDCLEAR
MSG1:<texto>
MSG2:<texto>
SETMONITOR=ON
SETMONITOR=OFF
```

### Diagnóstico / manutenção

```text
MAN
VER
TESTE
PING
SAFETY
IDENTIFY
CAPABILITIES
```

## Heartbeat

### PING

Entrada:

```text
PING
```

Resposta:

```text
PONG
$>
```

O Gateway utiliza PING como heartbeat interno enquanto existe movimento ativo.

## Segurança

### SAFETY

Entrada:

```text
SAFETY
```

Resposta atual:

```text
SAFETY:MOTION:ACTIVE
SAFETY:LAST_STOP:none
$>
```

ou:

```text
SAFETY:MOTION:STOPPED
SAFETY:LAST_STOP:control_watchdog
$>
```

### Eventos de parada

O Mega emite:

```text
SAFETY:STOP:<reason>
```

Reasons implementados:

```text
command
front_obstacle
rear_obstacle
motion_timeout
control_watchdog
```

Essas linhas são eventos observáveis e podem ocorrer fora da resposta de um comando normal.

## Health e autoteste

### HEALTH

Entrada:

```text
HEALTH
```

O Body Controller retorna linhas estruturadas:

```text
RBT:HEALTH:BODY:OK
RBT:HEALTH:SAFETY:IDLE
RBT:HEALTH:MOTION:STOPPED
RBT:TELEM:ULTRA_RE_CM:<valor>
RBT:TELEM:ULTRA_FRONT_CM:<valor>
RBT:TELEM:ULTRA_HEAD_CM:<valor>
$>
```

O Head Controller aceita:

```text
MCAB:HEALTH
```

e responde por meio da bridge com:

```text
MCAB:HEALTH:HEAD:OK
MCAB:POS:<x>,<y>
```

O Gateway 2.0 usa esses comandos em um autoteste não motor. A sequência inicia obrigatoriamente com `PARA` e não executa `FRENTE`, `RE`, `GESQ`, `GDIR` nem testes mecânicos.

## Identificação

### IDENTIFY

Entrada:

```text
IDENTIFY
```

Resposta implementada:

```text
RBT:IDENTIFY:BODY:MEGA2560:1.3
$>
```

Formato:

```text
RBT:IDENTIFY:<role>:<board>:<firmware_version>
```

## Descoberta de capacidades

### CAPABILITIES

Entrada:

```text
CAPABILITIES
```

Resposta atual contém uma linha por capacidade:

```text
RBT:CAP:MOTION
RBT:CAP:SERVOS
RBT:CAP:ULTRASONIC
RBT:CAP:ANALOG_SENSORS
RBT:CAP:GPS
RBT:CAP:LCD
RBT:CAP:MCABECA_BRIDGE
RBT:CAP:SAFETY_WATCHDOG
$>
```

Formato:

```text
RBT:CAP:<capability>
```

Clientes devem ignorar capacidades desconhecidas.

## MCabeca

O Gateway e o Mega usam namespace:

```text
MCAB:<comando>
```

Exemplos aceitos pelo Gateway:

```text
MCAB:DIST
MCAB:GETPOS
MCAB:CENTER
MCAB:LASERON
MCAB:LASEROFF
MCAB:SCANNING
MCAB:POINT:90,45
MCAB:LEDAZUL=ON
MCAB:LEDVERDE=OFF
MCAB:LEDVERMELHO=ON
MCAB:OLHOS=ON
MCAB:LIGHTAUTO=OFF
```

O Mega encaminha o conteúdo após `MCAB:` ao Head Controller.

## Erros

O protocolo legado ainda utiliza a mensagem:

```text
Comando não reconhecido!
```

A Rev. 4 reserva o prefixo estruturado:

```text
RBT:ERR:<code>
```

para evolução futura.

Enquanto `RBT:ERR` não estiver implementado em todos os controladores, clientes devem continuar aceitando as mensagens legadas.

## Prefixos reservados

A Rev. 4 reserva:

```text
RBT:IDENTIFY:
RBT:CAP:
RBT:OK:
RBT:ERR:
RBT:EVENT:
RBT:STATE:
SAFETY:
MCAB:
```

## Versionamento

### Device Protocol 1.x

Características:

- protocolo textual;
- compatibilidade com comandos históricos;
- prompt `$>`;
- extensões aditivas permitidas.

### Device Protocol 2.x

Reservado para uma futura quebra explícita de compatibilidade, caso seja necessária.

Nenhuma migração para 2.x deve acontecer silenciosamente.

## Política de depreciação

Para remover ou alterar semanticamente um comando existente:

1. documentar o comando afetado;
2. manter período de compatibilidade;
3. oferecer substituto;
4. atualizar Gateway, simulador e testes;
5. validar no hardware;
6. somente então considerar remoção numa versão major futura.

## Segurança para clientes

Um cliente não deve:

- enviar texto de LLM diretamente à serial;
- inventar comandos;
- assumir que envio significa execução;
- assumir que movimento continuará indefinidamente.

Um cliente deve:

- usar catálogo validado;
- esperar `$>` quando aplicável;
- observar eventos `SAFETY:STOP`;
- consultar estado após ações críticas;
- tratar perda de comunicação como estado inseguro/desconhecido.

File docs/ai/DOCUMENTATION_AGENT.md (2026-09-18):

# Agente de Documentação do Robotinics

## Objetivo

Permitir que uma IA ajude a manter a documentação sincronizada com código, hardware e arquitetura ao longo do tempo.

## Entradas

O agente lê:

- `AGENTS.md`;
- READMEs;
- código-fonte;
- `docs/rev3/`;
- histórico de commits quando disponível;
- resultados de compilação/teste;
- metadados de hardware documentados.

## Saídas

Pode produzir:

- relatório de inconsistências;
- links quebrados;
- comandos não documentados;
- pinos divergentes;
- arquivos sem README;
- documentação desatualizada;
- proposta de atualização;
- diff Markdown.

## Regra de evidência

Cada alteração documental deve indicar origem:

```text
SOURCE=CODE
SOURCE=README
SOURCE=REV3
SOURCE=TEST
SOURCE=USER
SOURCE=PROPOSAL
```

`PROPOSAL` nunca pode ser apresentado como funcionalidade existente.

## Fluxo

```text
scan repository
      |
      v
build module inventory
      |
      v
compare code <-> docs
      |
      v
classify divergence
      |
      v
generate patch
      |
      v
human review
      |
      v
commit
```

## Atualização por módulo

Quando o Mega mudar:

- revisar `Software/arduino/robotinics/README.*`;
- revisar protocolo;
- revisar integração Raspberry.

Quando MCabeca mudar:

- revisar comandos;
- pinagem;
- LEDs;
- laser;
- distância;
- integração Mega;
- visão se a interface angular mudar.

Quando Raspberry/IA mudar:

- revisar `Software/raspberry/AI/`;
- revisar `docs/ai/`;
- revisar variáveis de ambiente;
- revisar dependências TCHATGPT;
- revisar política de internet.

## Idiomas

Para mudanças estruturais:

1. atualizar Português;
2. replicar semanticamente para English;
3. replicar semanticamente para Español.

Não traduzir nomes de comandos ou protocolo.

## Links

Preferir links relativos para arquivos internos.

O agente deve detectar referências a arquivos removidos ou renomeados.

## Estado documental

Use quando necessário:

```text
CURRENT
HISTORICAL
DEPRECATED
PROPOSED
```

## Atualização em tempo útil

O agente pode rodar:

- a cada PR;
- a cada release;
- quando protocolo mudar;
- quando novo módulo surgir;
- quando firmware mudar comandos ou pinagem.

Ele deve gerar proposta ou aviso. Não deve alterar `master` automaticamente sem revisão.

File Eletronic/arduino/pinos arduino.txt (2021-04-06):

azul 6
cinza 7
amarelo 8
verde 9
marron 10
roxo 11
vermelho 12
branco 44
laranja 45
cinza 46

motor
26,28,30,32,34,36

rf tx,rx 25,27

lcd serial serial 20,21

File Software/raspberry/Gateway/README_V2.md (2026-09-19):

# Robotinics Gateway 2.0

Gateway local entre aplicações de alto nível e o Body Controller.

## Compatibilidade

As rotas `/v1` continuam disponíveis.

A Rev. 4 adiciona `/v2` sem remover a API anterior.

## Estados de conexão

```text
DISCONNECTED
CONNECTING
CONNECTED
DEGRADED
```

O estado está disponível em:

```text
GET /v2/state
```

## Prioridades

A fila é uma `PriorityQueue`.

Ordem padrão:

```text
0   emergency
10  high
50  normal
90  low
```

`PARA` usa prioridade 0.

Heartbeat interno `PING` usa prioridade 90.

## Envio síncrono

```http
POST /v2/command
Content-Type: application/json

{
  "command": "IDENTIFY"
}
```

## Envio assíncrono

```http
POST /v2/command

{
  "command": "ULTRA1",
  "async": true
}
```

Resposta:

```json
{
  "ok": true,
  "request_id": "...",
  "priority": 50
}
```

Consultar:

```text
GET /v2/request/<request_id>
```

## Cancelamento

```http
POST /v2/cancel/<request_id>

{
  "reason": "operator_cancel"
}
```

Se a requisição ativa cancelada for de movimento, o Gateway agenda um `PARA` de prioridade máxima.

## Retry

Retry automático é aplicado por padrão apenas a comandos classificados como seguros para repetição, por exemplo:

- `PING`;
- `IDENTIFY`;
- `CAPABILITIES`;
- `SAFETY`;
- consultas de sensores.

Movimentos não recebem retry automático por padrão.

Configuração:

```text
ROBOTINICS_COMMAND_RETRIES
```

Também é possível definir `retries` por requisição.

## Eventos

```text
GET /v2/events
GET /v2/events?limit=20
```

Eventos incluem:

- conexão;
- requisição enfileirada;
- retry;
- cancelamento;
- conclusão;
- safety stop;
- linhas estruturadas do dispositivo.

## Métricas

`GET /v2/state` retorna:

```text
submitted
completed
failed
cancelled
retried
serial_reconnects
events
```

## Telemetria

O Gateway converte respostas legadas conhecidas para estado estruturado quando possível:

- `ULTRA` -> `sensors.ultra_cm`;
- `ULTRA1` -> `sensors.ultra1_cm`;
- `ULTRA2` -> `sensors.ultra2_cm`;
- `CORR` -> `sensors.current`;
- `GAS` -> `sensors.gas`;
- `MCAB:DIST` -> `head.distance_cm`;
- `MCAB:POS` -> posição da cabeça.

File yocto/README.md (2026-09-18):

# Robotinics Yocto Image

[English](README.en.md) · [Español](README.es.md) · [Projeto](../README.md)

Esta pasta monta a imagem Linux reproduzível do Raspberry Pi para o Robotinics.

## Base

- Yocto Project 6.0 Wrynose LTS
- Poky
- meta-openembedded
- meta-raspberrypi
- meta-robotinics
- systemd
- arquitetura 64-bit

Máquinas previstas:

- raspberrypi4-64 como padrão
- raspberrypi5 como alternativa

## Estrutura

    yocto/
    ├── kas/
    ├── scripts/
    └── meta-robotinics/
        ├── conf/
        ├── recipes-core/
        └── recipes-robotinics/

## Build rápido

Instale kas e execute:

    cd yocto
    ./scripts/build.sh rpi4

Para Raspberry Pi 5:

    ./scripts/build.sh rpi5

Validação de metadados:

    ./scripts/check-layer.sh

## Conteúdo da imagem

A imagem robotinics-image instala:

- SSH
- Ethernet/Wi-Fi via NetworkManager
- Python 3
- pyserial e requests
- ferramentas USB/I2C
- gateway serial Robotinics
- estrutura de configuração em /etc/robotinics
- estado persistente em /var/lib/robotinics
- base da camada de IA
- voz com eSpeak quando a feature speech está habilitada
- V4L2/OpenCV quando a feature vision está habilitada

## Gateway serial

O serviço robotinics-gateway.service abre a serial do Mega em 115200 bps por padrão e registra o último estado conhecido em:

    /var/lib/robotinics/gateway-state.json

A IA não recebe acesso direto à serial.

## Configuração

Arquivo principal:

    /etc/robotinics/robotinics.env

Variáveis importantes:

    ROBOTINICS_SERIAL_PORT=/dev/ttyACM0
    ROBOTINICS_SERIAL_BAUD=115200
    ROBOTINICS_LLM_URL=
    ROBOTINICS_LLM_MODEL=
    ROBOTINICS_LLM_TOKEN=
    ROBOTINICS_DOCS_PATH=/opt/robotinics/docs

Tokens reais não devem ser gravados no repositório.

## TCHATGPT

A receita robotinics-tchatgpt-src fixa o snapshot do TCHATGPT no commit:

    e593fb758801cecb087e55e3222fc513cc35fee2

Ela é propositalmente uma receita de desenvolvimento e não entra na imagem padrão. O objetivo é fornecer uma fonte reproduzível para o trabalho de cross-compilação ARM64.

A validação do runtime deve ocorrer em etapas:

1. Free Pascal no target ou SDK
2. openai_core
3. TCHATGPT console mínimo
4. serial/gateway
5. RAG
6. Agent
7. visão e voz
8. serviço Robotinics AI

Só depois o runtime deve ser habilitado por padrão.

## Scripts históricos

Os antigos srvMonitor2 e srvFala não são instalados na imagem porque possuem problemas de segurança e robustez já registrados na Rev. 3. A imagem reaproveita a funcionalidade necessária em serviços novos.

Os scripts antigos de voz foram substituídos pelos comandos:

    robotinics-speak "texto"
    robotinics-read-file arquivo.txt

## Features

Nos manifests kas:

    ROBOTINICS_FEATURES ?= "vision speech"

Para uma imagem menor, remova vision ou speech.

## Próxima etapa

- validar parsing completo com bitbake
- compilar a imagem em host Yocto suportado
- testar boot no Raspberry físico
- confirmar serial do Mega
- validar câmera
- validar áudio
- criar receita de cross-compile do aplicativo TCHATGPT
- integrar atualização OTA posteriormente

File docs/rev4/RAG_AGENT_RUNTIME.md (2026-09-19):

# RAG e Agent Runtime — Rev. 4

## RAG local

A recuperação documental deixou de usar apenas presença simples de palavras.

O ranking atual combina:

- frequência de termos;
- comprimento do documento;
- frequência documental;
- peso BM25-like;
- boost para ocorrência no título;
- boost para ocorrência no caminho;
- metadados por documento.

Cada trecho entregue ao LLM inclui metadados JSON:

```json
{
  "path": "...",
  "title": "...",
  "score": 1.23,
  "tokens": 420
}
```

Isso melhora rastreabilidade e permite evoluir futuramente para FTS/SQLite e embeddings sem mudar o contrato com o AI Runtime.

## Ferramentas tipadas

O Agent Runtime conhece atualmente três tipos de ferramenta:

```text
gateway.read
gateway.diagnostic
gateway.command
```

A política é aplicada fora do prompt, em `actionpolicy.pas`.

## Classificação de risco

```text
READ_ONLY
DIAGNOSTIC
PHYSICAL_LOW
PHYSICAL_HIGH
FORBIDDEN
```

Leituras e diagnósticos não exigem confirmação.

`PARA` é permitido sem confirmação porque reduz risco físico.

Comandos de movimento e atuadores exigem confirmação humana explícita antes de execução.

Comandos não catalogados são negados.

## Limite atual

A política já está implementada como unidade tipada e integrada ao prompt do AI Runtime, mas o runtime ainda não executa autonomamente ações físicas. Isso é intencional: a próxima evolução deve criar um executor de ferramentas que consulte a política, solicite confirmação quando necessário e então use exclusivamente o Gateway.

## Próximos passos

- índice FTS persistente;
- embeddings opcionais;
- busca híbrida lexical + semântica;
- executor de ferramentas;
- confirmação humana persistida na tarefa;
- correlação de evidências entre tool call, Gateway e resultado observado.

## Índice persistente e embeddings

O runtime agora pode criar um índice persistente em JSON.

Variáveis:

```text
ROBOTINICS_RAG_INDEX
ROBOTINICS_RAG_REBUILD
ROBOTINICS_EMBEDDING_URL
ROBOTINICS_EMBEDDING_TOKEN
ROBOTINICS_EMBEDDING_MODEL
```

Sem `ROBOTINICS_EMBEDDING_URL`, o índice funciona em modo lexical.

Quando configurado, cada documento recebe um embedding obtido de endpoint compatível com:

```http
POST /v1/embeddings
```

A busca combina:

```text
final_score =
  lexical_weight * lexical_score_normalizado +
  semantic_weight * cosine_similarity
```

O peso lexical padrão é 0,65.

## Executor de ferramentas

`toolrunner.pas` aplica a `ActionPolicy` antes de qualquer chamada ao Gateway.

O runtime também oferece um modo explícito:

```text
robotinics-ai --tool gateway.read state
robotinics-ai --tool gateway.diagnostic diagnostics
robotinics-ai --tool gateway.command ULTRA1
robotinics-ai --tool gateway.command FRENTE --confirm
```

Sem `--confirm`, comandos classificados como `PHYSICAL_HIGH` ficam em `WAITING_CONFIRMATION` e não chegam ao Gateway.

Cada execução cria uma tarefa, registra confirmação, decisão da policy, resultado/erro e persiste auditoria.

## SQLite FTS5 incremental

Quando embeddings não estão configurados, o runtime utiliza um índice SQLite FTS5 persistente.

Variável:

```text
ROBOTINICS_RAG_FTS_DB
```

Padrão:

```text
<ROBOTINICS_STATE_PATH>/rag/index.sqlite
```

A sincronização compara cada documento por:

- caminho;
- tamanho;
- timestamp de modificação.

Com isso:

- arquivo novo -> inserido;
- arquivo alterado -> reindexado;
- arquivo inalterado -> preservado;
- arquivo removido -> removido do índice.

A tabela FTS5 utiliza BM25 nativo do SQLite para ranking.

O runtime usa esta estratégia:

```text
sem embeddings:
  SQLite FTS5 incremental
       |
       v
  fallback lexical simples

com embeddings:
  índice híbrido JSON
       |
       +--> lexical
       +--> embeddings/cosseno
```

Assim o modo local não precisa reconstruir todo o corpus a cada consulta.

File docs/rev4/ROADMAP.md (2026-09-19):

# Roadmap executável — Robotinics Rev. 4

Este roadmap transforma a proposta da Rev. 4 em entregas verificáveis.

## Fase 1 — Baseline e dívida técnica

### Entregáveis
- [x] arquitetura alvo documentada;
- [x] roadmap documentado;
- [x] regras de compatibilidade documentadas;
- [ ] inventário automático de código e hardware;
- [ ] mapa comando -> função -> hardware;
- [ ] lista de dependências Arduino;
- [ ] matriz de funcionalidades atual/proposta/histórica.

### Critério de conclusão
É possível identificar, a partir da documentação, onde cada responsabilidade reside e quais interfaces não podem ser quebradas.

---

## Fase 2 — Firmware Mega

### Atividades
- [x] extrair pinagem para arquivo dedicado;
- [x] separar motores;
- [x] separar servos;
- [x] separar sensores;
- [x] separar display;
- [x] separar GPS/RF/comunicações auxiliares;
- [x] extrair parser de comandos;
- [~] reduzir uso de `String` — buffers de recepção já migrados; mensagens e compatibilidade ainda usam `String`;
- [ ] eliminar código morto;
- [~] corrigir bugs sem alterar protocolo — corrente, ultrassom, buffers e inicialização RF corrigidos; validação em hardware pendente;
- [ ] criar camada de telemetria;
- [x] criar SafetyController — margem de colisão, STOP prioritário, watchdog lógico e timeout de movimento implementados; validação em hardware pendente.

### Compatibilidade obrigatória
Os comandos legados devem continuar aceitos durante esta fase.

### Critério de conclusão
O firmware compila para Mega, executa o protocolo atual e cada subsistema pode ser mantido isoladamente.

---

## Fase 3 — MCabeca

### Atividades
- [ ] separar pan/tilt;
- [ ] separar ultrassom;
- [ ] separar laser;
- [ ] separar LEDs/olhos;
- [ ] documentar limites;
- [ ] padronizar respostas;
- [ ] criar health/status;
- [ ] adicionar testes básicos.

### Critério de conclusão
O Head Controller possui API física previsível e não depende de lógica cognitiva.

---

## Fase 4 — Robotinics Device Protocol

### Atividades
- [x] catalogar comandos atuais;
- [x] catalogar formatos de resposta atuais;
- [~] definir `OK`, `ERR` e eventos — namespaces reservados e `SAFETY:STOP` implementado; `RBT:OK/ERR/EVENT` completo ainda pendente;
- [x] definir versionamento 1.x/2.x;
- [x] definir heartbeat `PING/PONG`;
- [x] definir e implementar `IDENTIFY`;
- [x] definir e implementar `CAPABILITIES`;
- [x] definir política de compatibilidade;
- [x] definir depreciação futura.

### Critério de conclusão
Um software pode implementar um cliente Robotinics sem ler o firmware.

---

## Fase 5 — Safety Layer

### Atividades
- [x] STOP prioritário;
- [x] watchdog lógico de comunicação;
- [x] timeout para movimento contínuo;
- [x] estado seguro na perda de comunicação;
- [ ] limites dos servos;
- [x] catálogo de comandos permitido no Gateway;
- [ ] política para ações vindas de agente;
- [~] registro de falhas — Gateway registra `SAFETY:STOP:*`; persistência consolidada ainda pendente;

### Critério de conclusão
Falha no Raspberry, LLM ou aplicação de usuário não pode manter movimento indefinido.

---

## Fase 6 — Gateway 2.0

### Atividades
- [x] estados de conexão explícitos;
- [x] heartbeat durante movimento;
- [x] fila com prioridade;
- [x] cancelamento;
- [x] retry configurável;
- [~] telemetria estruturada — sensores legados e MCabeca convertidos para estado; expansão de GPS/ACEL ainda pendente;
- [x] eventos;
- [x] API versionada v1/v2;
- [x] testes unitários;
- [~] métricas e diagnóstico — métricas operacionais implementadas; diagnóstico avançado ainda pendente.

### Critério de conclusão
Clientes de alto nível não precisam conhecer detalhes da serial.

---

## Fase 7 — Simulator

### Atividades
- [x] dispositivo serial virtual;
- [x] simulador Body Controller;
- [x] simulador Head Controller;
- [x] sensores configuráveis;
- [~] cenários de falha — colisão, watchdog, timeout, drop de resposta e desconexão modelados; expansão futura pendente;
- [ ] replay de telemetria;
- [x] testes de protocolo.

### Critério de conclusão
Gateway e AI Runtime podem ser testados sem o robô físico.

---

## Fase 8 — CI

### Pipeline
- [x] compile Mega;
- [x] compile MCabeca;
- [x] syntax/smoke test Gateway;
- [x] protocol tests;
- [ ] compile Free Pascal AI Runtime;
- [x] smoke/integration test do simulador;
- [ ] validação de links;
- [ ] validação Yocto.

### Critério de conclusão
Push e pull request já compilam Mega e MCabeca e executam validações básicas do Gateway; os demais checks continuam incrementais.

---

## Fase 9 — Telemetria e diagnóstico

### Atividades
- [x] modelo de estado unificado;
- [x] health por módulo;
- [x] autoteste — sequência segura implementada no Gateway, iniciando por `PARA` e sem comandos de movimento;
- [x] diagnóstico guiado;
- [~] histórico — comandos/eventos e relatórios de manutenção persistidos; replay/histórico dedicado de telemetria ainda pendente;
- [x] relatório de manutenção JSON persistente com evidências, diagnóstico, health, sensores, falhas e métricas.

---

## Fase 10 — Task Engine 2.0

### Atividades
- [x] tarefas;
- [x] subtarefas;
- [x] dependências;
- [x] tentativas;
- [x] cancelamento;
- [x] evidências;
- [x] resultado;
- [x] persistência;
- [x] auditoria.

---

## Fase 11 — RAG e Agent Runtime

### Atividades
- [x] busca lexical melhorada;
- [x] BM25/FTS — ranking BM25-like e índice SQLite FTS5 incremental implementados;
- [x] metadata;
- [x] embeddings opcionais — endpoint compatível com OpenAI configurável por ambiente;
- [x] busca híbrida — score lexical normalizado combinado com similaridade cosseno de embeddings;
- [x] ferramentas tipadas;
- [x] política de ações;
- [x] confirmação humana para operações físicas relevantes.

---

## Fase 12 — Visão e voz

### Visão
- [ ] captura;
- [ ] detecção;
- [ ] tracking;
- [ ] integração pan/tilt;
- [ ] calibração;
- [ ] fusão câmera + distância.

### Voz
- [ ] STT;
- [ ] TTS;
- [ ] interação;
- [ ] controle de sessão;
- [ ] integração ao Task Engine.

---

## Fase 13 — Control Center

### Telas
- [ ] dashboard;
- [ ] estado;
- [ ] sensores;
- [ ] atuadores;
- [ ] câmera;
- [ ] tarefas;
- [ ] IA;
- [ ] logs;
- [ ] diagnóstico;
- [ ] manutenção;
- [ ] configuração.

---

## Fase 14 — Robotinics OS

### Atividades
- [ ] validar build ARM64 completo;
- [ ] consolidar recipes;
- [ ] serviços systemd;
- [ ] health checks;
- [ ] watchdog;
- [ ] configuração;
- [ ] atualização;
- [ ] imagem Raspberry Pi 4;
- [ ] imagem Raspberry Pi 5;
- [ ] procedimento de recuperação.

## Ordem recomendada de execução

```text
Firmware
  -> protocolo
  -> safety
  -> gateway
  -> simulador
  -> CI
  -> telemetria
  -> diagnóstico
  -> Task Engine
  -> RAG/agente
  -> visão/voz
  -> interface
  -> distribuição
```

A inteligência deve crescer sobre uma base física verificável, não substituir essa base.

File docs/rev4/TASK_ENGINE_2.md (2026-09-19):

# Task Engine 2.0 — Robotinics Rev. 4

## Objetivo

O Task Engine transforma uma pergunta ou objetivo em uma unidade persistente e auditável de trabalho.

Ele não controla hardware diretamente. Ações físicas continuam passando pelo Gateway, catálogo de comandos e Safety Layer.

## Schema

Cada tarefa persistida possui:

```text
schema_version
id
question
status
cancelled
cancel_reason
result
created_at
updated_at
steps
subtasks
evidence
audit
```

## Estados da tarefa

Estados usados atualmente:

```text
RUNNING
DONE
ERROR
CANCELLED
```

## Subtarefas

Cada subtarefa possui:

```text
id
name
kind
depends_on
status
attempts
detail
created_at
started_at
finished_at
```

Estados:

```text
PENDING
RUNNING
DONE
ERROR
CANCELLED
```

## Dependências

`depends_on` contém IDs de subtarefas separados por vírgula.

Uma subtarefa só pode iniciar quando todas as dependências deixaram os estados:

```text
PENDING
RUNNING
```

Isso permite que uma etapa de raciocínio continue mesmo quando uma fonte opcional terminou com `ERROR`, desde que o erro esteja registrado como evidência/auditoria.

## Tentativas

Cada chamada de `StartSubTask` incrementa `attempts`.

Isso permite registrar retries de fontes externas ou operações de alto nível sem perder o histórico da tarefa.

## Evidências

Evidências possuem:

```text
timestamp
source
kind
detail
```

O AI Runtime já registra:

- pergunta original;
- estado do Gateway;
- catálogo;
- histórico;
- contexto documental;
- contexto externo quando habilitado;
- resposta ou erro do LLM.

## Resultado

O resultado final é persistido separadamente em `result`.

Uma tarefa concluída não depende de logs textuais para reconstruir a resposta apresentada ao usuário.

## Cancelamento

`Cancel(reason)`:

- marca a tarefa como `CANCELLED`;
- registra o motivo;
- cancela subtarefas ainda `PENDING` ou `RUNNING`;
- grava evento de auditoria.

Cancelamento de uma ação física deve continuar sendo propagado ao Gateway. O Task Engine não substitui o mecanismo de cancelamento do Gateway 2.0.

## Auditoria

Eventos incluem, entre outros:

```text
task_created
status
step
subtask_created
subtask_running
subtask_done
subtask_error
task_cancelled
evidence
result
```

Cada evento contém timestamp e detalhe.

## Persistência

Arquivos são salvos em:

```text
<ROBOTINICS_STATE_PATH>/tasks/<task-id>.json
```

A gravação usa arquivo temporário seguido de rename para reduzir risco de arquivo parcialmente escrito.

## Integração atual do AI Runtime

Fluxo atual:

```text
Entender solicitação
        |
        +--> Coletar estado do robô
        |
        +--> Consultar documentação
        |
        +--> Consultar fonte externa
                    |
                    v
             Gerar resposta final
```

A etapa final depende das três fontes de contexto terem terminado, com sucesso ou erro documentado.

## Segurança

O Task Engine pode planejar e registrar ações, mas:

- não escreve PWM;
- não movimenta servos diretamente;
- não envia texto arbitrário à serial;
- não transforma conteúdo web em comando físico;
- deve utilizar Gateway/catalog/policy para qualquer ação física futura.

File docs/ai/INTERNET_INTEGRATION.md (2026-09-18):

# Integração do Robotinics com a Internet

## Objetivo

Permitir que o Raspberry Pi consulte a internet para complementar respostas e diagnóstico sem transformar conteúdo externo em comando de hardware.

## Arquitetura

```text
TAIAgent
   |
   v
InternetTool
   |
   +-- Search Adapter
   +-- HTTP/API Adapter
   +-- Chromium Adapter
   |
   v
Content Extractor
   |
   v
Source Cache
   |
   v
Context Builder
   |
   v
TCHATGPT
```

## Formas de acesso

### APIs HTTP

Preferidas quando existe serviço estruturado.

Exemplos:

- documentação técnica;
- meteorologia;
- APIs públicas;
- serviços internos.

### Busca web

Um adaptador de busca retorna URLs e metadados. A busca deve ser uma ferramenta separada do LLM.

### Navegação

`TAIChromiumBrowser` pode ser utilizado para páginas que exigem navegação ou renderização, desde que CEF esteja validado no Raspberry escolhido.

Como Chromium/CEF pode ser pesado em ARM, HTTP simples deve ser preferido quando suficiente.

## Contrato do InternetTool

Entrada sugerida:

```text
query
max_results
allowed_domains
timeout
max_bytes
purpose
```

Saída sugerida:

```json
{
  "query": "manual do componente",
  "retrieved_at": "ISO-8601",
  "sources": [
    {
      "url": "https://...",
      "title": "...",
      "summary": "..."
    }
  ]
}
```

## Cache

Resultados devem ter TTL de acordo com a natureza da informação.

Exemplos:

- datasheet: dias;
- documentação web: horas;
- notícia: minutos;
- clima: minutos.

## Internet + RAG

Conteúdo web útil pode ser colocado em índice temporário:

```text
web -> sanitize -> chunk -> temporary RAG -> answer
```

Esse índice deve registrar origem e expirar.

## Regras de segurança

Não executar automaticamente:

- scripts encontrados em páginas;
- comandos shell sugeridos por conteúdo externo;
- firmware baixado da internet;
- alterações de configuração;
- comandos do robô extraídos diretamente de uma página.

## Falhas

Se internet estiver indisponível:

- informar a limitação;
- usar documentação local quando possível;
- não inventar conteúdo ausente;
- não bloquear controle local.

## Credenciais

Tokens ficam fora do Git:

```text
ROBOTINICS_LLM_TOKEN
ROBOTINICS_SEARCH_TOKEN
ROBOTINICS_LLM_URL
ROBOTINICS_SEARCH_URL
```

Use variáveis de ambiente ou arquivo protegido fora do repositório.

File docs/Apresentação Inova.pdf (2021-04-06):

| 2014

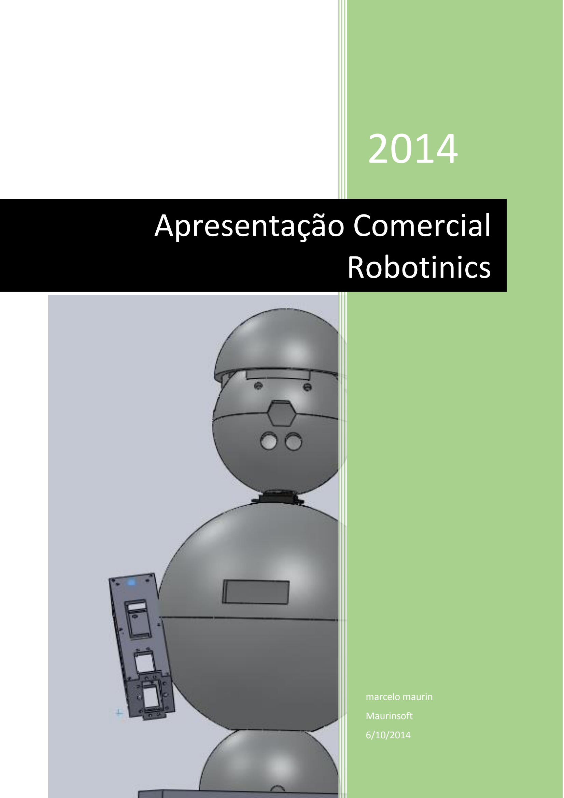
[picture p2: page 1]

Apresentação Comercial | | Robotinics

marcelo maurin

Maurinsoft

6/10/2014

## Sumário

## Propósito do Projeto Robotinics

Ser plataforma aberta para desenvolvimento de soluções de autômatos.

## Mercado Atual

Hoje, o mercado atual de projetos robóticos se divide em dois grandes grupos:

1. Automação Industrial – Projetos customizados e de grande custo, figurando na casa dos milhares de dólares.
2. Projetos Educacionais de Automação – Kits de desenvolvimento educacional, contendo pequeno número de itens que montados e encaixados permitem alguma interação, porém sem apelo comercial e com hardware e software proprietário.

## Tendências

A proliferação de projetos abertos e customizáveis e as inovações tecnológicas no ramo da mecânica (prototipagem rápida) , da eletrônica (Arduino open hardware) e o barateamento de peças e componentes de automação criaram a possibilidade de um mercado que ainda não é atendido.

Hoje com um aumento cada vez maior em bricolagem i
, criando um mercado neste segmento, torna possível que pessoas que antes não tinham acesso pelo elevado custo a profissionais e técnicas, hoje tem oportunidade de desenvolvimento em áreas que antes não eram permitidas.

Melhoria e popularização da eletrônica e aparecimento de micro controladores rápidos e flexíveis. Melhora e popularização das plataformas open hardware iipara eletrônica. Tornaram possível a criação de projetos complexos e bem estruturados sobre uma plataforma rápida e barata.

O desenvolvimento de software também está cada vez mais enraizado no nosso dia a dia. Apesar de existir um mercado muito grande de empresas e produtos fechados, o mercado cada vez mais recebe contribuições de softwares gratuitos, Open Source¹

1 O termo código aberto, ou open source em inglês, foi criado pela OSI (http://pt.wikipedia.org/wiki/OSI) (Open Source Initiative) e não refere-se a software também conhecido por software livre, (http://pt.wikipedia.org/wiki/Software_livre) pois respeita as quatro liberdades definidas pela Free Software Foundation, (http://pt.wikipedia.org/wiki/Free_Software_Foundation)
(Fonte: Wikipédia)

i bricolagem (português brasileiro) (http://pt.wikipedia.org/wiki/Portugu%C3%AAs_brasileiro) ou bricolage/bricolagem (português europeu) (http://pt.wikipedia.org/wiki/Portugu%C3%AAs_europeu)1 (http://pt.wikipedia.org/wiki/Bricolagem#cite_note-1)
têm ambas origem
que vem do francês bricolage, é usado nas atividades em que você mesmo realiza para seu próprio uso ou consumo, evitando deste modo, o emprego de um serviço profissional. (fonte: wikipédia)
iiiiiiiiii Hardware livre é um hardware eletrônico (http://pt.wikipedia.org/wiki/Hardware) projetado e oferecido da mesma maneira que um software de código livre. (http://pt.wikipedia.org/wiki/C%C3%B3digo_livre) O termo foi primeiramente empregado para refletir o lançamento irrestrito de informação (http://pt.wikipedia.org/wiki/Informa%C3%A7%C3%A3o) sobre o projeto de hardware, tal como
um diagrama, (http://pt.wikipedia.org/wiki/Diagramas_de_circuito) estrutura de produtos (http://pt.wikipedia.org/wiki/Estrutura_de_produtos) e dados de layout de uma placa de circuito impresso. (http://pt.wikipedia.org/wiki/Placa_de_circuito_impresso)

1 (http://pt.wikipedia.org/wiki/Hardware_livre#cite_note-info-1)
(fonte: Wikipédia)

## Alvo

O público alvo deste projeto são:

- Hobistas – Amantes da robótica e da eletrônica
- Empreendedores – Pessoas que tem visão de mercado e pretendem desenvolver equipamentos específicos para uso de automação.
- Escolas e centros de ensino – Cursos técnicos e superiores na área de eletrônica, mecânica ou Informática para apresentação e desenvolvimento de trabalhos na área fim.
- Segurança – Como o produto permite o monitoramento e gerenciamento de espaços, os projetos robóticos também podem ser empregados para controle de segurança de casas e empresas.
- Home care – Permite que você acompanhe idosos ou crianças de forma remota.
- Apresentação em empresas – Permite que o robô faça a apresentação da empresa dando a primeira boa vinda de clientes, incluindo acompanhando o mesmo até o local em que precise ir.
- Telepresença – Permite que clientes e fornecedores, mesmo em locais físicos diferentes, consigam interagir e se comunicar, através de um avatar pessoal.

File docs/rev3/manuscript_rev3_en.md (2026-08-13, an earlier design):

---
title: "Robotinics Rev. 3"
subtitle: "Robotics, IoT, and Artificial Intelligence with Arduino, Raspberry Pi, and TCHATGPT"
author: "Marcelo Maurin Martins"
edition: "Third revised and expanded edition"
date: "2026"
language: "en-US"
dedication: "To my beloved wife, Daniela Machado. Eternal love."
---

# Introduction to the third edition

Robotinics began as a multidisciplinary project: a ground robot open to experimentation, built with 3D-printed parts, accessible electronics, Arduino, Raspberry Pi, and free and open-source software. The first edition documented a real journey of research and construction. This third edition preserves that historical value while reorganizing the material so that it once again works as a technical manual.

The main change is not merely an update to software versions. The architecture was revised to separate responsibilities, correct calculations, and incorporate artificial intelligence without giving a language model unrestricted control of the robot. Arduino remains responsible for deterministic and real-time tasks. Raspberry Pi coordinates services, sensors, and communication. The TCHATGPT project provides the layer for language models, agents, voice, vision, memory, RAG, and observability. A mandatory validation and safety layer sits between every AI decision and any actuator.

This edition was built on two frozen references:

| Project | Editorial reference | Purpose |
|---|---|---|
| Robotinics | commit `61d2a19d10e6701e27e46181e1a6c740b8ee4e30` | Mechanics, electronics, firmware, and historical archive |
| TCHATGPT | commit `15d5e1a7780088701716896cfe9fb3afe0e7b71a` | Lazarus/Free Pascal components for AI and integration |

Freezing these references does not prevent future development. It only ensures that readers can relate the text to the code. Newer versions may be adopted after their differences have been verified.

> [!WARNING]
> This is an educational and experimental project. It includes motors, lithium-ion batteries, tools, soldering, and moving parts. Do not work on an energized system, do not assemble improvised lithium chargers, and do not make mains-voltage connections based solely on this book. Use certified modules, adequate protection, and supervision by a qualified person.

## What was corrected

Corrections in this edition include, among others:

- series-cell capacity and the nominal and maximum voltage of a 3S pack;
- the CC/CV charging process, protection, and balancing of lithium cells;
- correct multimeter use for voltage and current measurements;
- the distinction between force, torque, power, energy, and capacity;
- traction, slope, and arm-torque calculations;
- LED current and sizing of the current-limiting resistor;
- definitions of normally open and normally closed relay contacts;
- actual buck-converter limits and separation of motor, servo, and logic power rails;
- the L298N description, PWM speed control, and component limitations;
- HC-SR04 frequency, code examples, and timing requirements;
- safety and memory problems in the historical C/C++ servers;
- conflicting ports and commands, and files absent from the current repository;
- outdated Linux, database, PHP, OpenCV, voice, and remote-access practices;
- navigation, references, terminology, and editorial organization.

A detailed matrix appears in Appendix C.

## How to use this book

The project is divided into five parts. Part I defines requirements, architecture, and safety. Part II covers mechanics, power, and electronics. Part III presents firmware, Linux, and communication. Part IV integrates TCHATGPT. Part V guides assembly, testing, and evolution.

Readers do not need to install every tool to build the robot. Those who only want to reproduce the prototype can use the ready-made files. Those who intend to modify parts, boards, or software should work from the version-controlled sources. In both cases, every stage ends with acceptance criteria: do not proceed until the current subsystem is stable.

## Conventions

- Voltage values are given in volts (V), current in amperes (A), power in watts (W), energy in watt-hours (Wh), force in newtons (N), and torque in newton-meters (N·m).
- Numerical examples are instructional. When a real component has a different datasheet, the datasheet takes precedence.
- Literal commands, filenames, and identifiers appear in monospaced type.
- Sections marked **Experimental** have not been sufficiently validated on the indicated platform.
- The term **AI** includes language models, vision, voice, classification, and agents. It does not imply unrestricted autonomy.

# Acknowledgments

This work is the result of years of study, construction, and collaboration. Marcelo Maurin Martins remains grateful to God, his family, friends, professors at Centro Paula Souza, ETEC, and FATEC, and everyone who reviewed or supported the original project. The memory of Professor Danilo continues to be honored in this edition.

The Arduino, Raspberry Pi, Free Pascal, Lazarus, and free and open-source software communities are also recognized; their work makes it possible to build and share projects such as Robotinics.

# Part I - Project, architecture, and safety

# 1. Robotinics as a learning platform

## 1.1 Robot, IoT, and cyber-physical system

A robot is an electromechanical system capable of sensing its environment, processing information, and producing actions. An Internet of Things device collects or receives data and exchanges it with other systems. Robotinics belongs to both groups: it has sensors, actuators, local processing, network communication, and services that can be integrated with external applications.

This definition is useful because it prevents the project from being reduced to a single board. Behavior emerges from cooperation among the mechanical structure, power supply, electronics, firmware, operating system, and applications. A power failure may look like a software error. Motor noise may corrupt a sensor reading. Network delay may make a motion command unsafe. The complete system is therefore the unit of design.

## 1.2 Rev. 3 objectives

The third edition adopts the following verifiable objectives:

1. Keep the robot controllable when the network or AI is unavailable.
2. Prevent free-form text from being converted directly into a motor signal.
3. Allow deterministic discovery of the commands published by the firmware.
4. Separate traction, servo, and logic power.
5. Record the version, state, and failures of every subsystem.
6. Run staged tests before full assembly.
7. Offer local and remote AI modes without requiring a specific provider.
8. Preserve compatibility with the mechanical archive and historical commands when doing so does not compromise safety.

## 1.3 Intended audience

This book is intended for students, teachers, makers, and developers who want to understand integration across several fields. It does not assume professional experience in all of them, but it does require care. A beginner can reproduce low-risk stages; activities involving batteries, high current, tools, or structural modifications should be performed with suitable guidance.

For programmers, Robotinics provides a real case study involving embedded systems, protocols, Lazarus, Free Pascal, C/C++, Linux, vision, voice, and AI. For electronics and mechanical professionals, it shows how to transform physical components into an observable and programmable system.

## 1.4 Repository organization

In the adopted snapshot, the main files are located at:

| Area | Reference path | Contents |
|---|---|---|
| Mechanics | `Mecanic/solidwork` and `Mecanic/stl` | Assemblies, parts, and 3D-printing files |
| Electronics | `Eletronic/eagle`, `Eletronic/pcb` | Boards, drawings, and historical manufacturing files |
| Arduino | `Software/arduino` | Main firmware and head firmware |
| Raspberry | `Software/raspberry` | Services, camera, voice, and historical applications |
| Database and web | `Software/database` and `Software/site` | Scripts and historical interface |
| Book | `docs` | PDF of the previous edition |

Some Lazarus tools mentioned in the previous edition were removed from the main branch in 2022. They remain recoverable from the history, but they must not be presented as though they were available in the current clone. Rev. 3 replaces their role with examples based on the modular TCHATGPT packages.

## 1.5 Documentation strategy

Concepts, calculations, architecture, and test criteria belong in the book. Installation sequences that change frequently should remain in version-controlled repository documentation. This separation reduces obsolescence: the book teaches why and how to validate, while the repository provides the exact command compatible with a given version.

Before starting, record the following on a build sheet:

- mechanical revision of the parts;
- Arduino and Raspberry Pi board models;
- model, chemistry, and declared battery capacity;
- motor and servo models;
- firmware version;
- commits of the Robotinics and TCHATGPT projects;
- operating system and architecture;
- AI provider or local server;
- bench-test results.

# 2. Third-edition architecture

## 2.1 Separation of responsibilities

The architecture uses layers. Arduino performs low-level control: motors, servos, simple readings, timing, limits, and stopping. Raspberry Pi runs the robot services: communication, capture of high-volume sensor data, supervision, and integration. TCHATGPT interprets intent, organizes context, and coordinates AI components. The human interface presents requests and confirms sensitive actions.

[FIGURE:architecture]

This separation is deliberate. Language models are probabilistic and may produce an incorrect response. Motors require predictable behavior. The model may suggest a structured action; only the validator decides whether the action is in the catalog, whether its parameters are in range, and whether the robot state permits execution.

## 2.2 Command path

The safe path of a request is:

1. The user speaks or types an intent.
2. The system converts the input to text and includes only the necessary context.
3. The agent asks the model for a response in a structured format.
4. A parser validates the structure; text outside the contract is not executed.
5. The command is compared with the catalog discovered through `MAN`.
6. The safety policy validates state, parameters, limits, and the need for confirmation.
7. The user confirms physical actions when required.
8. The command is sent to Arduino.
9. The firmware applies its own limits and watchdog.
10. Telemetry confirms the result, and the agent informs the user.

[FIGURE:command_pipeline]

The model is never the only barrier. If it invents a command, the catalog blocks it. If it uses an out-of-range parameter, the validator blocks it. If communication stops, the watchdog interrupts motion. If an obstacle is detected, the firmware can stop without consulting the AI.

## 2.3 Deployment profiles

### Profile A - validated controller

The Lazarus application with TCHATGPT runs on Windows x64 or Linux x64. Raspberry Pi acts as the gateway and onboard computer. This is the recommended profile for the first build because these platforms have stronger evidence of support in the TCHATGPT project.

### Profile B - AI embedded on Raspberry Pi

The Lazarus application and compatible packages run on Raspberry Pi ARM64. The model may be remote or local. In the snapshot used for this edition, ARM64 is classified as experimental; this profile therefore requires compilation, dependency testing, and validation of every component before controlling actuators.

### Profile C - local operation without cloud services

TCHATGPT uses a local OpenAI-compatible endpoint, such as llama.cpp or neural-api. This profile avoids sending robot data to an external provider, but it requires memory, storage, and computing capacity appropriate for the model. On limited hardware, a small model can handle classification and short commands while vision and voice use specialized components.

## 2.4 Operating states

The robot uses at least four states:

| State | Motion | Query commands | Allowed transition |
|---|---:|---:|---|
| `DISARMED` | Blocked | Allowed | To `ARMED` after verification and confirmation |
| `ARMED` | Allowed within limits | Allowed | To `EXECUTING`, `DISARMED`, or `FAULT` |
| `EXECUTING` | Current action only | Telemetry allowed | Returns to `ARMED` or moves to `FAULT` |
| `FAULT` | Blocked with safe output | Diagnostics allowed | To `DISARMED` after correction and reset |

[FIGURE:safety_states]

`STOP` and `DISARM` must be accepted in every state. Loss of heartbeat, timeout, critical undervoltage, overcurrent, or activation of the emergency-stop button leads to a safe output without depending on Raspberry Pi.

## 2.5 Interfaces

The protocol between the controller and Arduino is text-based, line-delimited, and suitable for terminal debugging. A production version may evolve to frames with length, sequence, and integrity checking, but it should retain a human-readable diagnostic mode.

Between network services, prefer authenticated connections, restricted binding, and size-limited messages. Historical servers that accepted commands on every interface and forwarded data to a shell are not part of the recommended architecture.

# 3. Safety and working method

## 3.1 Safety hierarchy

Safety is implemented in independent layers:

1. **Mechanical:** gear guards, secure mounting, center of gravity, and no accessible pinch points.
2. **Electrical:** fuse, master switch, reverse-polarity protection, BMS, properly sized wires, and suitable connectors.
3. **Firmware:** limits, timeout, watchdog, obstacle stopping, and disarmed state at startup.
4. **Application:** command catalog, ranges, confirmation, authentication, and logging.
5. **AI:** constrained prompt, structured output, action limits, and no direct operating-system access.
6. **Operation:** clear area, supervision, emergency-stop button, and test procedure.

No layer authorizes removal of the next one. A well-written prompt does not replace a watchdog; a fuse does not replace current limiting in the design; an on-screen confirmation does not replace a physical button.

## 3.2 Bench rules

- Perform initial tests with the wheels raised off the surface.
- Use a current-limited bench supply before using the battery.
- Connect one subsystem at a time.
- Never adjust wiring while the system is energized.
- Keep the emergency-stop button within reach.
- Test `STOP` before any motion command.
- Remove arms and loads from servos during initial movements.
- Do not charge lithium cells inside the robot without suitable thermal design and protection.
- Do not leave the pack charging unattended.
- Record idle current, peak current, and temperature.

## 3.3 Change control

Every change should answer four questions:

1. Which requirement motivated the change?
2. Which files and components were changed?
3. How was the change tested?
4. How can the previous version be restored?

Firmware, application, and documentation should report their versions. A published version of the book should point to a repository tag; pointing only to `main` or `master` makes reproduction dependent on future changes.

## 3.4 Stage completion criteria

A stage is complete when:

- the assembly matches the drawing or a recorded modification;
- there are no loose wires, visible shorts, or unexpected heating;
- consumption is within the power budget;
- all expected commands respond;
- simulated failures lead to a safe state;
- results have been recorded with date and version;
- the next subsystem can be added without hiding earlier failures.

## 3.5 Credential and data security

API keys must not be stored in the repository or in a readable `settings.ini`. The TCHATGPT serial-agent example has a historical option for storing a token as plain text; this edition does not adopt it. Use an environment variable, operating-system vault, or protected file outside the project directory.

Camera, microphone, telemetry, and conversation data may contain personal information. When a remote provider is used, inform the operator, send only what is necessary, and apply a retention policy. For educational use, prefer controlled environments and non-identifying data.

## 3.6 Stated limitations

Robotinics is not a medical device, certified industrial equipment, a vehicle for carrying people, or a safety-critical platform. Use in another context requires a risk analysis, applicable standards, and professional validation. Low-cost components and clones may have different specifications; always measure the actual unit.

# Part II - Mechanics, power, and electronics

# 4. Mechanical sizing

## 4.1 Requirements before selecting motors

A motor should not be selected solely from a commercial torque rating. First define mass, wheel diameter, speed, maximum slope, floor type, desired acceleration, and number of driven wheels. Then calculate the required effort and apply a margin.

Force and torque are not the same quantity. Force is measured in newtons. Torque is the product of force and the perpendicular distance to the axis and is measured in newton-meters. A force of 10 N applied 0.05 m from the axis produces 0.5 N·m.

## 4.2 Motion forces

On a slope at angle `θ`, the component of weight opposing motion is:

```text
F_slope = m × g × sin(θ)
```

The approximate rolling resistance is:

```text
F_rolling = Crr × m × g × cos(θ)
```

For acceleration:

```text
F_acceleration = m × a
```

At low speed, Robotinics aerodynamic drag tends to be small compared with the other components, but it can be included when necessary. The total design force is the sum of the relevant components. Required wheel torque is:

```text
T_total = (F_total × wheel_radius) / efficiency
```

Divide the result among the wheels that are actually driven. Efficiency represents transmission, deformation, bearing, and floor-contact losses. Do not assume 100%.

## 4.3 Corrected traction example

Consider a 12 kg robot with two driven wheels, a radius of 0.05 m, a 5° slope, an estimated rolling coefficient of 0.03, acceleration of 0.2 m/s², and overall efficiency of 70%.

| Component | Calculation | Approximate result |
|---|---|---:|
| Slope | `12 × 9.81 × sin(5°)` | 10.26 N |
| Rolling | `0.03 × 12 × 9.81 × cos(5°)` | 3.52 N |
| Acceleration | `12 × 0.2` | 2.40 N |
| Total | sum | 16.18 N |

Total axle torque is approximately `(16.18 × 0.05) / 0.70 = 1.16 N·m`. With two driven wheels, each geared-motor assembly must provide about `0.58 N·m` under the calculated condition. Applying a safety factor of 2 raises the target to approximately `1.16 N·m` per wheel, or about `11.8 kgf·cm`.

This value must be compared with the assembly's continuous torque, not only its stall torque. Continuous operation near stall heats the motor, increases consumption, and shortens its service life. Also confirm speed after reduction.

## 4.4 Grip and traction limit

Even a powerful motor cannot move the robot if the wheel slips. The maximum transferable force depends on the normal load on the driven wheels and the coefficient of friction. The battery and heavy components should be placed low and distributed to maintain stability and grip without overloading a single support point.

Run a ramp test using small increments. Record slope, motor current, speed, temperature, and slipping. This test validates both the mechanical calculation and the electrical budget.

## 4.5 Arm torque

For a joint, add the moment produced by each mass relative to the axis:

```text
T_static = Σ (mass_i × g × distance_i)
```

Distance is measured between the axis and the item's center of mass. For the shoulder, include the masses of the upper arm, forearm, gripper, servos installed beyond the axis, and payload. The worst condition usually occurs with the arm horizontal.

Example: a 0.25 kg link with its center of mass 0.10 m away; a 0.20 kg distal assembly centered at 0.28 m; and a 0.10 kg payload at 0.40 m.

```text
T = (0.25 × 9.81 × 0.10)
  + (0.20 × 9.81 × 0.28)
  + (0.10 × 9.81 × 0.40)
  ≈ 1.19 N·m ≈ 12.1 kgf·cm
```

This is static torque only. Starting, stopping, backlash, impact, and misalignment require a margin. With a factor of 2.5, the joint would require approximately `3.0 N·m`, or `30.6 kgf·cm`. A servo advertised as 10 or 15 kgf·cm therefore cannot reliably meet this condition. Solutions include reducing length or mass, limiting payload, using a counterweight or spring, changing the transmission, or choosing a suitable actuator.

> [!NOTE]
> The traditional servo unit is `kgf·cm`, not `kgf·cm²`. For approximate conversion, `1 kgf·cm = 0.0981 N·m`.

## 4.6 Center of gravity and stability

The projection of the center of gravity onto the floor must remain within the polygon formed by the contact points. Extended arms shift the center and may tip the robot. Evaluate extreme positions in CAD and run a physical test with the robot unpowered.

Keep the battery and power supplies low in the structure. Use software to restrict pose combinations that bring the center of gravity close to the edge. AI may choose a task, but a deterministic planner must reject poses outside the validated envelope.

# 5. Structure and mechanical assembly

## 5.1 Mechanical archive

The repository contains SolidWorks parts, assemblies, and STL files. Major elements include the base, wheel supports, lower and upper body, Raspberry Pi mount, head, arm extensions, and grippers. STL files allow reproduction without the original CAD software; assembly files support deeper modifications.

[FIGURE:robot_cad]

Before printing, verify:

- units and scale;
- part revision and orientation;
- holes, clearances, and minimum thickness;
- space for nuts, screw heads, and connectors;
- load direction relative to print layers;
- interference between cables and moving parts;
- maintenance access.

## 5.2 Material and printing

PLA is easy to print and works for rigid prototypes, but it may lose strength at elevated temperatures and fracture at fitted joints. PETG offers greater toughness and thermal tolerance in many scenarios. ABS/ASA can be useful for functional parts when the printer and environment control warping and emissions. The choice depends on load, temperature, and printing capability.

Do not copy slicing parameters without validation. Record material, manufacturer, nozzle diameter, layer height, perimeter count, infill, and orientation. For motor mounts and joints, perimeters and orientation are often more important than high, randomly patterned infill.

## 5.3 Base

The base should be assembled and validated before the body. The recommended sequence is:

1. Inspect and finish the printed parts.
2. Assemble mounts, motors, and wheels without electronics.
3. Check parallelism and free rotation.
4. Position the battery and boards with templates, without final fastening.
5. Check the center of gravity and access to the master switch.
6. Install cable ducts, strain relief, and logic-ground points.
7. Perform a manual rolling test.

Misaligned wheels increase current and impair odometry. Measure the wheelbase on both sides and verify that the base is not twisted. Casters should provide support without lifting a driven wheel.

## 5.4 Body, arms, and head

The body houses boards, power distribution, and connections. Install removable panels and identify every harness. Arms should have stops or safe limits before power is applied. The head carries the camera, sensors, and positioning mechanisms; avoid routing cables through pinch zones.

[FIGURE:arm_cad]

For every joint, record:

| Item | Minimum record |
|---|---|
| Mechanical zero | physical reference position |
| Logical zero | value sent to the servo at that position |
| Minimum and maximum limits | collision-free range |
| No-load current | reference for detecting a stall |
| Maximum payload | validated condition, not merely advertised |
| Positive direction | convention used by the firmware |

## 5.5 Alternatives to 3D printing

The original concept allows volumes to be built from accessible materials such as sheets, profiles, and coated spherical elements. Any substitution must preserve fastening, rigidity, access, and protection. Expanded polystyrene should not be exposed to products that dissolve it; coatings and adhesives should first be tested on a sample.

## 5.6 Mechanical acceptance criteria

- No cracked or deformed parts.
- Critical screws use suitable thread locking and inspection marks.
- Wheels are free and aligned.
- Cables are not strained throughout the full range of motion.
- The center of gravity remains stable with the arms in allowed poses.
- Accidental contact with moving parts is prevented.
- The battery, fuse, and emergency stop remain accessible without extensive disassembly.

# 6. Power, battery, and distribution

## 6.1 Fundamental quantities

Voltage represents potential difference. Current represents the flow of charge. DC electrical power is `P = V × I`. Energy is power accumulated over time and may be expressed in Wh. Battery capacity in Ah is not energy by itself; voltage must also be considered.

In the previous edition, currents from different rails were added without converting power. The correct procedure is to calculate the power of each load on its rail, include converter efficiency, and then estimate current drawn from the battery.

## 6.2 3S pack

Consider three lithium-ion cells rated at 3.7 V nominal and 5.2 Ah connected in series:

| Property | Result |
|---|---:|
| Nominal voltage | `3 × 3.7 = 11.1 V` |
| Maximum charge voltage | `3 × 4.2 = 12.6 V`, when specified for the cell |
| Capacity | `5.2 Ah` |
| Approximate nominal energy | `11.1 × 5.2 = 57.7 Wh` |

In series, voltages add while capacity in Ah remains the same. A value of 15.6 Ah would correspond to three identical cells connected in parallel, not in series.

Values of 4.2 V per cell are common, but the manufacturer's datasheet is authoritative. Chemistry, charge limit, current, and temperature vary. Do not mix cells of different models, capacities, ages, or states.

## 6.3 Safe charging

Lithium cells require a CC/CV charger compatible with the number of cells and a suitable protection/balancing system. A BMS protects the pack, but it does not turn an ordinary power supply into a proper charger. For 3S, use a charger designed for 3S and the actual chemistry, with final voltage and current within specification.

Do not derive charge current from a universal rule such as `C/10`. Use the value recommended by the cell and pack manufacturers. Cells in series do not triple capacity for this calculation.

> [!DANGER]
> Rev. 3 does not teach how to build a mains-connected charger. Use certified equipment suitable for the pack. A swollen, damaged, hot, or abnormally charged cell must be isolated and disposed of according to local hazardous-waste guidance.

## 6.4 BMS, fuse, and master switch

The minimum architecture includes:

1. a safely assembled pack;
2. a BMS/protection device compatible with 3S, current, and chemistry;
3. a fuse near the positive battery terminal;
4. a master switch rated for direct current;
5. protected distribution for each rail;
6. polarized connectors with adequate capacity.

The fuse protects the conductor and reduces fault energy. Its rating must not exceed the safe capacity of wires and connectors. Starting currents must be considered to avoid nuisance opening without turning the fuse into a mere piece of wire.

[FIGURE:power_architecture]

## 6.5 Separate rails

DC motors, servos, and logic generate and tolerate noise differently. Rev. 3 uses separate rails:

- **Traction:** voltage compatible with motors and driver, with its own protection.
- **Servos:** high-current converter at the voltage allowed by the servos.
- **5 V logic:** Raspberry Pi and compatible peripherals, with margin for peaks.
- **3.3 V logic:** sensors or interfaces that require it.

Grounds may need a common signal reference, but distribution must prevent motor current from flowing through the logic return. Use star topology, appropriate conductors, decoupling, and oscilloscope verification when possible.

A "5 V/5 A" supply is not automatically sufficient for Raspberry Pi, servos, and peripherals. High-torque servos may produce large peaks. Size the system using measurements and margin, and never power several servos through the Arduino board regulator.

## 6.6 Converters

A buck converter reduces voltage. It cannot regulate 12.6 V from a 12 V input. Raising voltage requires a boost converter; operation both above and below the output requires buck-boost. In Robotinics, prefer an architecture in which converters operate comfortably within their specified ranges.

Check maximum voltage, actual continuous current, cooling, ripple, efficiency, and transient response. The current printed on inexpensive modules may represent a peak under ideal conditions rather than continuous operation.

## 6.7 Runtime

Approximate runtime can be estimated as:

```text
time_h ≈ (nominal_energy_Wh × usable_efficiency) / average_power_W
```

With 57.7 Wh, an overall usable efficiency of 80%, and average consumption of 35 W, the estimate is `(57.7 × 0.8) / 35 ≈ 1.32 h`. Motion, terrain, temperature, aging, and BMS limits affect the result. Validate it in a controlled test and do not discharge beyond the safe limit.

## 6.8 Capacitors and ripple

`20.75 × 10⁻³ F` equals `0.02075 F`, or `20,750 µF`; not 20.75 µF. In a rectified supply, a common approximation is:

```text
C ≈ I / (f_ripple × ΔV)
```

For 1 A, 120 Hz ripple, and a 1 V variation, `C ≈ 8,333 µF`. This example does not replace power-supply design or consideration of tolerance, ESR, capacitor voltage, and ripple-current rating.

## 6.9 Correct measurement

Voltage is measured in parallel. Current is measured in series with the load or by using an appropriate sensor. Placing a multimeter set to current directly between positive and negative creates a low-resistance short circuit and may blow a fuse, damage probes or the circuit, or cause an accident.

Before measuring:

- confirm the selected terminals and function;
- start with an appropriate range;
- de-energize before changing a series connection;
- respect the instrument category, voltage, current, and fuse ratings;
- use a clamp or sensor when the series method is unsafe.

## 6.10 Electrical acceptance criteria

- Polarity and continuity verified without the battery.
- Fuses installed and identified.
- Each rail remains within tolerance, both unloaded and under load.
- Ripple and voltage drop are acceptable during motor/servo starting.
- Idle and peak currents are recorded.
- No connector or wire heats beyond expectation.
- BMS and charger are compatible and documented.
- Undervoltage and shutdown are tested in a controlled manner.

# 7. Electronics, sensors, and actuators

## 7.1 Arduino and logic levels

The historical firmware was developed for Arduino Mega, which normally uses 5 V logic. Raspberry Pi GPIO uses 3.3 V and is not directly 5 V tolerant. Every connection between boards must account for level, direction, current, and startup state. Use a level shifter when needed; never rely only on a coincidental bench result.

## 7.2 Motor driver

The L298N is a dual H-bridge based on bipolar transistors. It supports direction control and speed control through PWM applied to its enable pins. It does not provide galvanic isolation and has significant voltage drop and dissipation, especially at low motor voltage.

If retained for compatibility, measure motor voltage and driver temperature at worst-case load. In an electronics revision, a modern MOSFET driver sized for voltage, starting current, and braking will usually provide better efficiency.

Motors appear with different voltage ratings in historical sections. Rev. 3 does not assume 12 V: identify the installed model and follow its datasheet. A battery voltage of 11.1/12.6 V does not authorize direct connection of a 3-6 V motor.

## 7.3 Relays

A normally open (NO) contact remains open when the coil is de-energized and closes when energized. A normally closed (NC) contact remains closed at rest and opens when energized. Check the component diagram, coil voltage, contact current, and need for a flyback diode.

## 7.4 LEDs

`0.02 A` is 20 mA, not 200 mA. The resistor is calculated as:

```text
R = (V_supply - V_LED) / I_LED
```

For a 5 V supply, a red LED with an approximate 2 V drop, and a desired current of 9 mA, `R ≈ 333 Ω`; 330 Ω is an appropriate standard value in this example. Calculate resistor power as `P = I² × R` and confirm the actual LED specification.
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

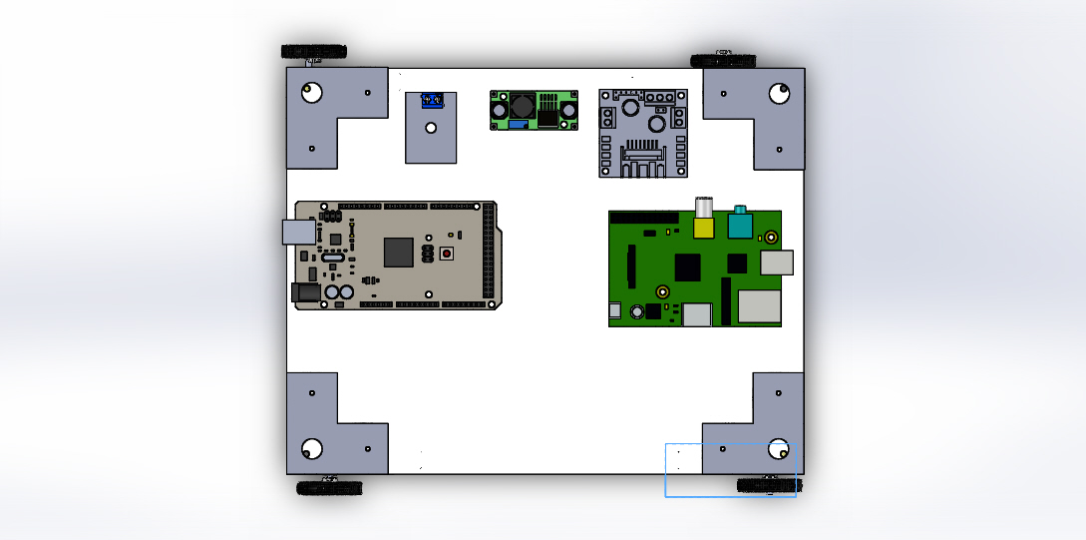
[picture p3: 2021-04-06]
Mecanic/solidwork/Visão das Placas.JPG

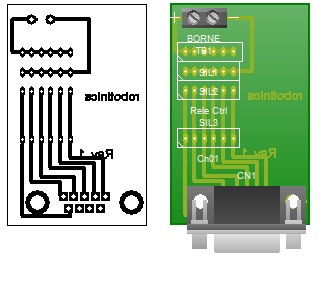
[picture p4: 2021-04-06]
Eletronic/pcb/visao placa02.jpg

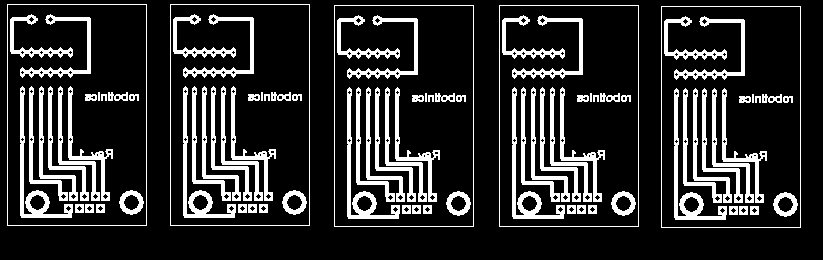
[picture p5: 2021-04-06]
Eletronic/pcb/Espelho placa02.bmp

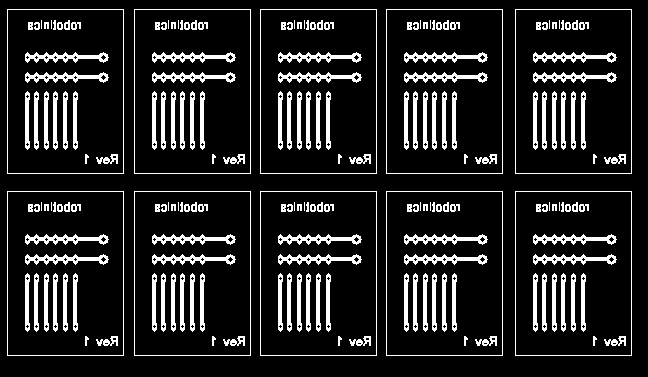
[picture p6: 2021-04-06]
Eletronic/pcb/Espelho placa controladora de servo motor.bmp

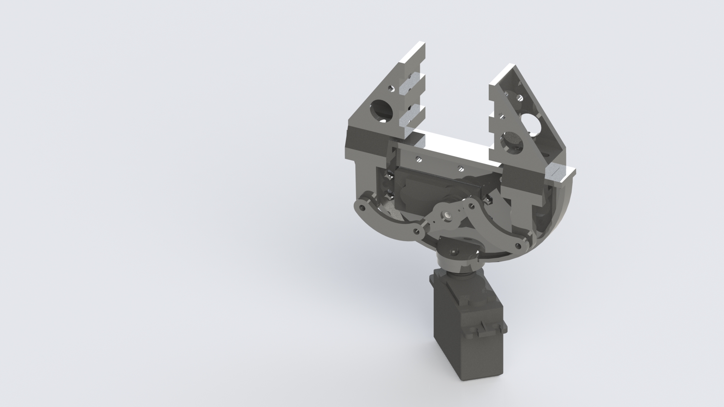
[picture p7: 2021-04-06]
Mecanic/solidwork/garra/1499/1499d.JPG

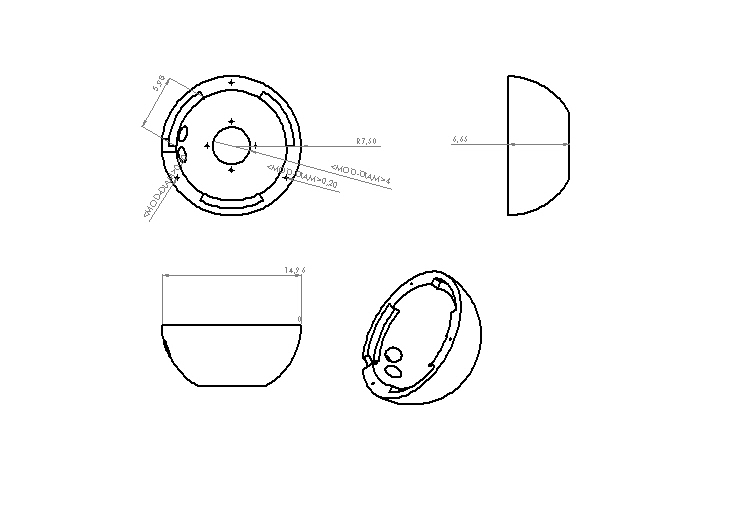
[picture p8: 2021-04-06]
Mecanic/solidwork/VisaoBasePeqInf.JPG

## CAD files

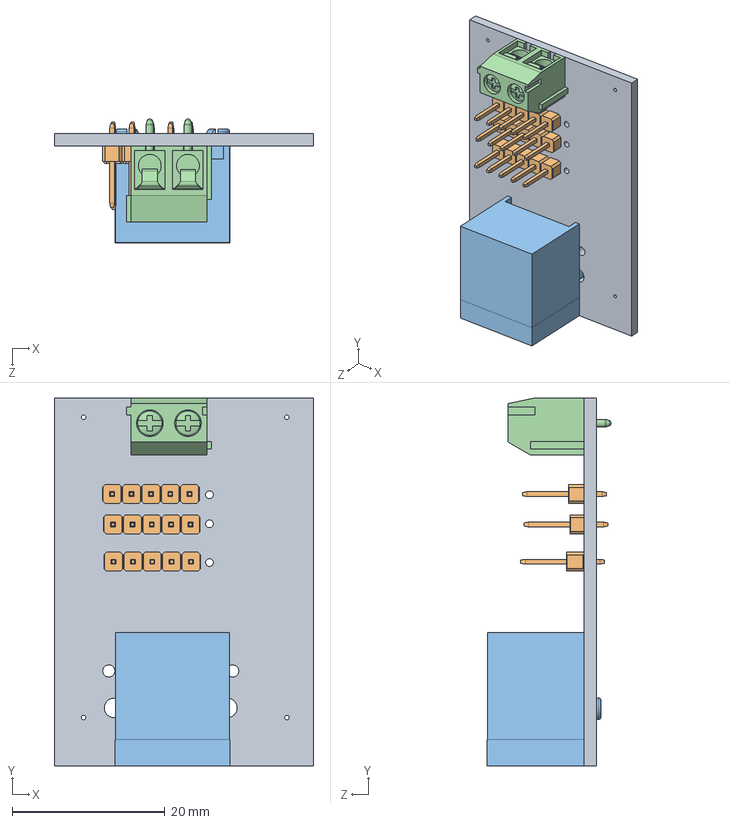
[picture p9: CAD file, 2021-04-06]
Eletronic/eagle/Placa Controladora de Servomotor/placa controladora de servomotor.SLDASM
34.0 x 48.2 x 16.2 mm
placa controladora de servomotor
Header 2_54 Vertical 1x5 x 3
RJ-45
Borne

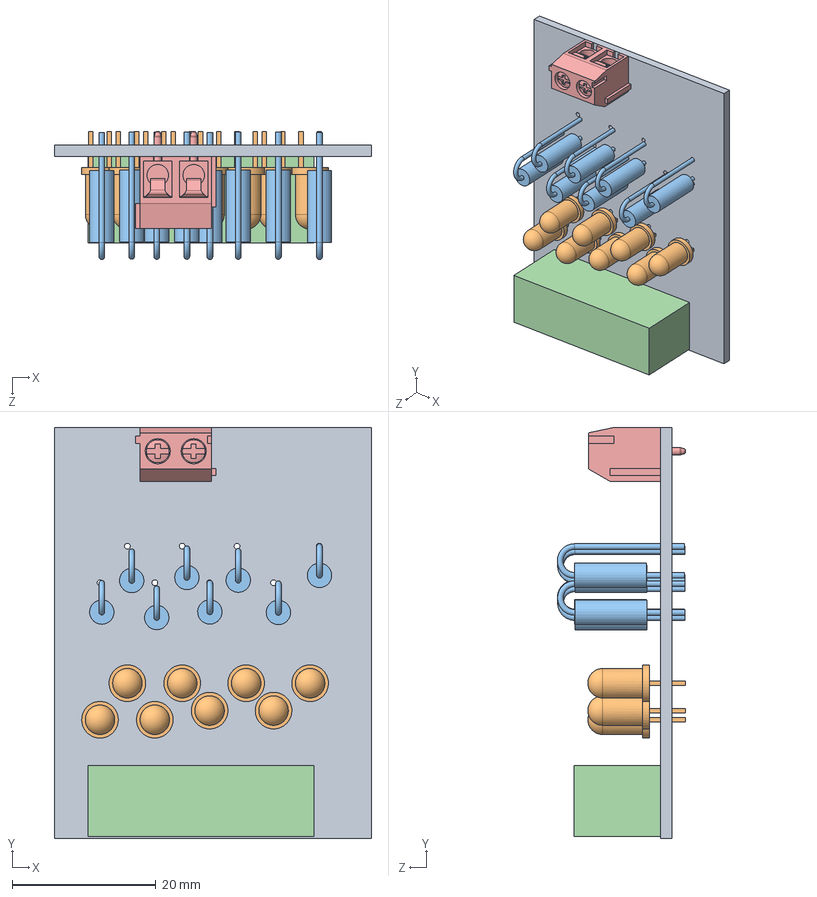
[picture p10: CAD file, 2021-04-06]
Eletronic/eagle/Placa de Leds/placaled/placaled.SLDASM
44.1 x 57.1 x 17.8 mm
placaled
5mm LED RED x 8
0_5W Metal Film Resistor x 8
KK1568_5V
Borne

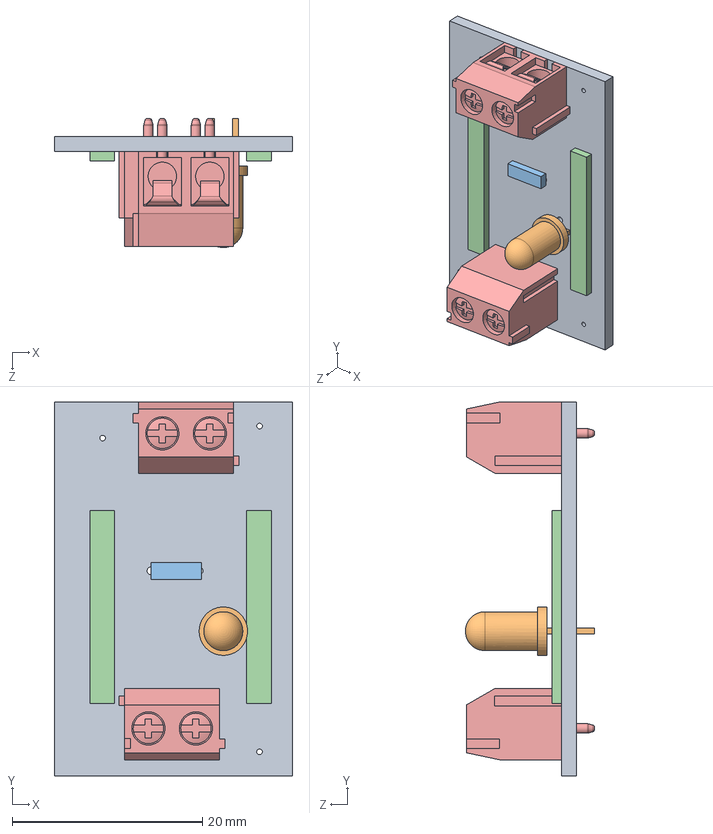
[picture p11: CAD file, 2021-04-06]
Eletronic/eagle/placa de distribuicao 5V/placa distribuidora 5v.SLDASM
25.1 x 39.4 x 13.6 mm
placa distribuidora
5mm LED RED
MA081_MA081 x 2
Borne x 2

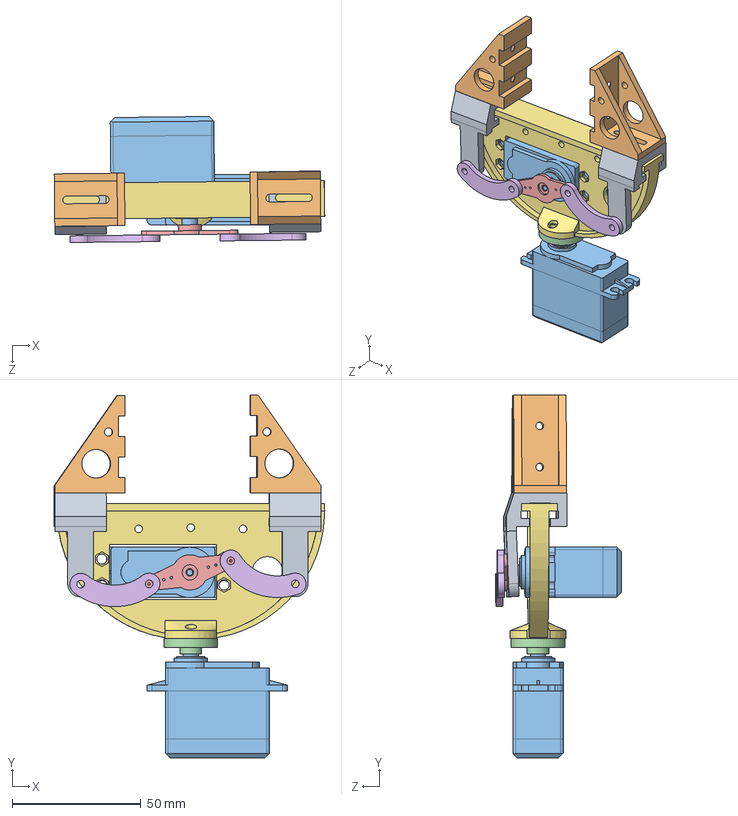
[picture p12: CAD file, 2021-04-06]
Mecanic/solidwork/garra/1499/1499.SLDASM
105.2 x 141.1 x 49.0 mm
base pinza x 2
pinza x 2
Servo4.3kilos_TR205 x 2
corona 1 servo 4.3 Kg.
corona 1 servo 3.4 Kg.
brazo curvo x 2
riel

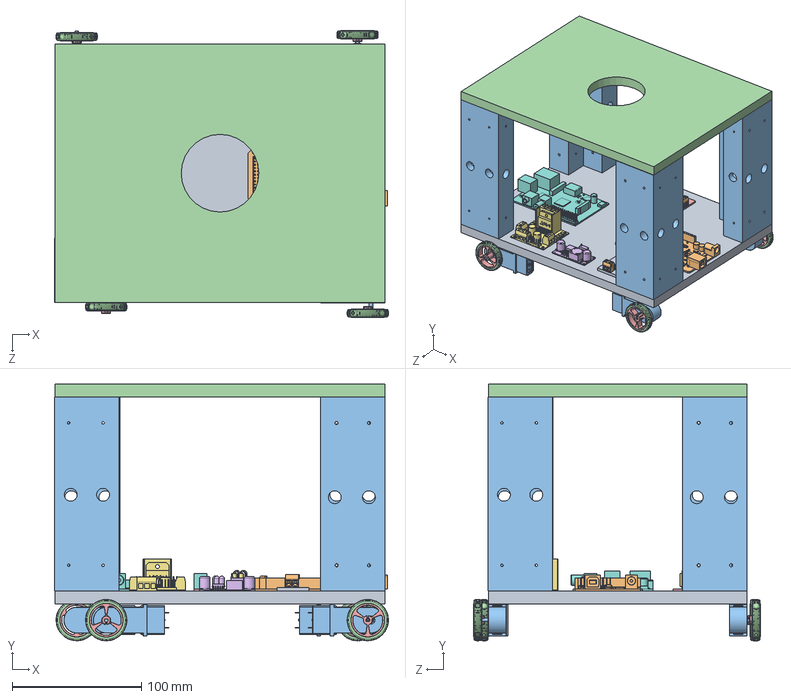
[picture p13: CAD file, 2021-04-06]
Mecanic/solidwork/Capitulo04.SLDASM
258.1 x 198.4 x 221.6 mm
BaseRodas
ArduinoMega
Pololu Motor x 4
Pololu-Wheel-32x7mm-tire x 4
Pololu-Wheel-32x7mm-rim x 4
stepdown voltage converter
L298N
raspberry pi
Sensor Corrente
Borne x 2
Prolongador x 4
BaseReta
placaled
5mm LED RED x 8
0_5W Metal Film Resistor x 8
KK1568_5V

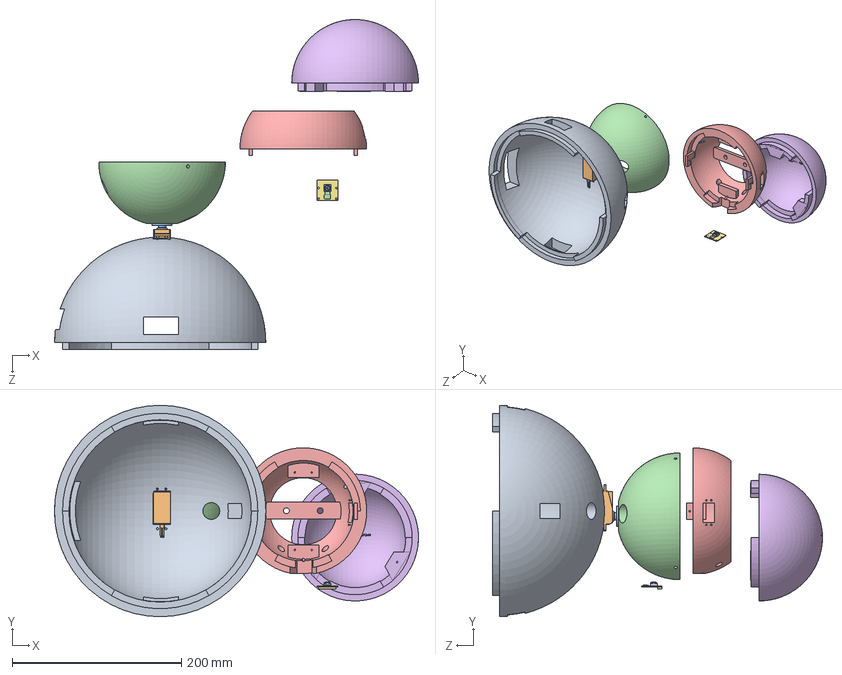
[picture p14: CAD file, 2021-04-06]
Mecanic/solidwork/MONTAGEMCABECA.SLDASM
430.5 x 250.0 x 390.3 mm
BaseGrandeSup
Servo
Horn
cabecainf
cabecasup
chapeu
RasPi_Camera_Board
OVA5647
OVA5647_Housing
OVA5647_IR-Glas
OVA5647_Lens
OVA5647_Pigtail

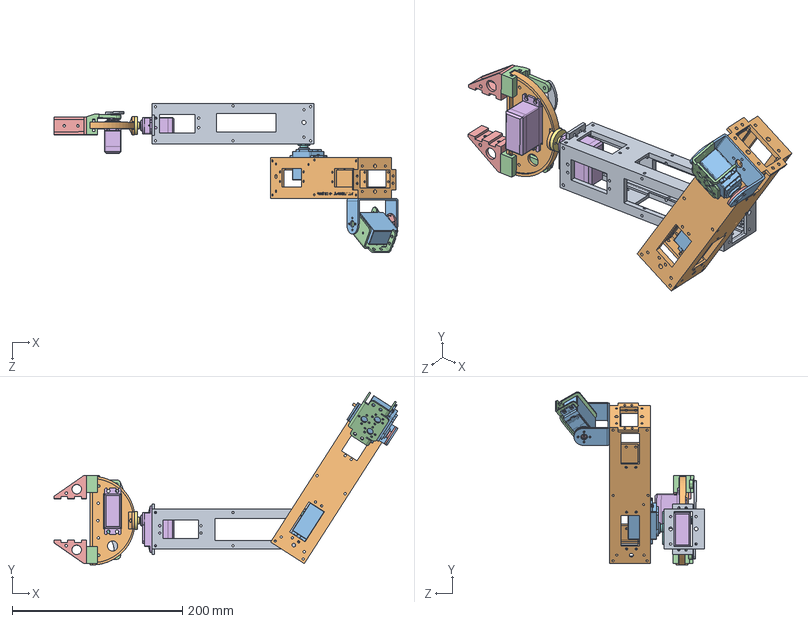
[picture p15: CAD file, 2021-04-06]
Mecanic/solidwork/montagem braço.SLDASM
403.7 x 203.0 x 175.3 mm
BRACO_BASE
BRACO_EXTENSAO
HS-475HB_001 x 2
base pinza x 2
pinza x 2
Servo4.3kilos_TR205 x 2
corona 1 servo 4.3 Kg.
corona 1 servo 3.4 Kg. x 2
brazo curvo x 2
riel
U Bracket1
Multi Purpose Bracket
Horn

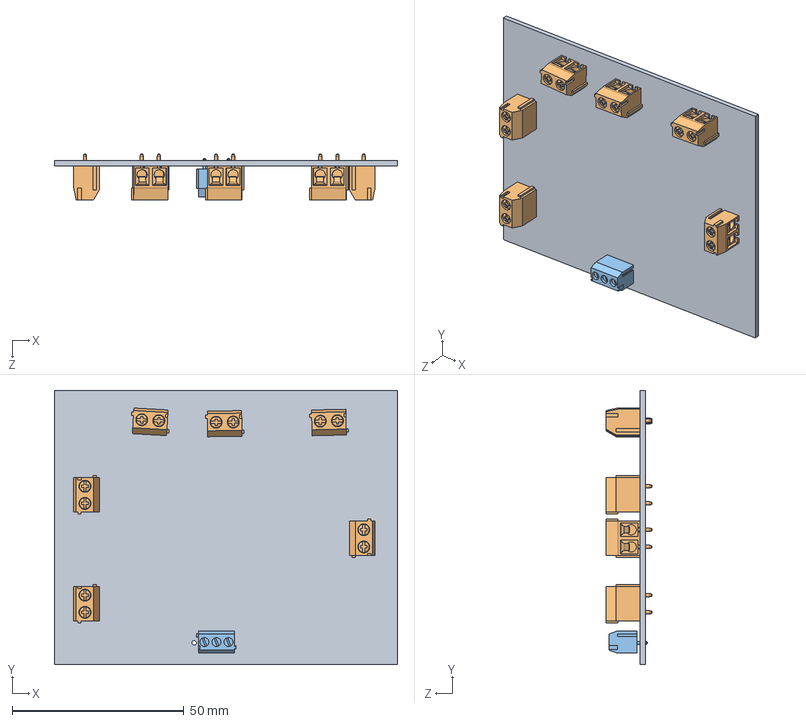
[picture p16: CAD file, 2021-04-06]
Mecanic/solidwork/placa do circuito do carregador.SLDASM
100.0 x 80.0 x 13.5 mm
placa do circuito do carregador
Borne x 6
ETB08_03

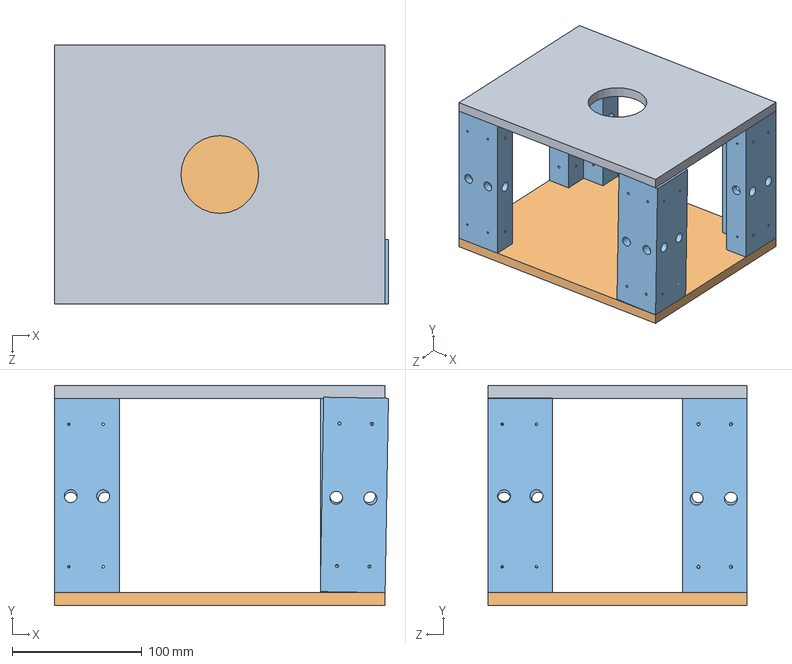
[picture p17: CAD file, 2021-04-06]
Mecanic/solidwork/Base Robo.SLDASM
257.6 x 170.0 x 200.0 mm
BaseReta
BaseRodas
Prolongador x 4

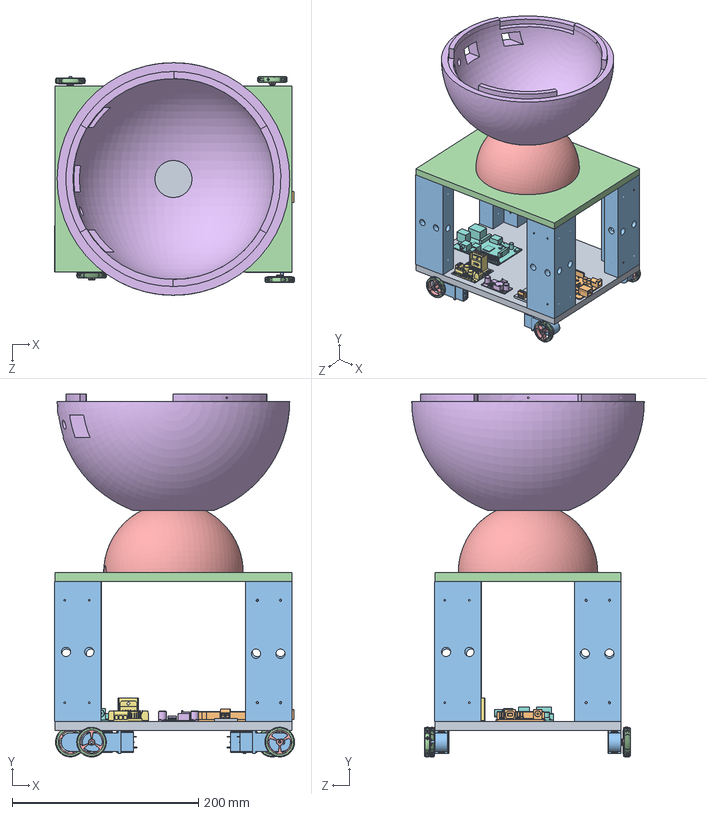
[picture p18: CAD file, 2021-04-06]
Mecanic/solidwork/Capitulo05.SLDASM
258.1 x 390.1 x 250.0 mm
BaseRodas
ArduinoMega
Pololu Motor x 4
Pololu-Wheel-32x7mm-tire x 4
Pololu-Wheel-32x7mm-rim x 4
stepdown voltage converter
L298N
raspberry pi
Sensor Corrente
Borne
Prolongador x 4
BaseReta
BasePeqInf
BaseGrandeInf

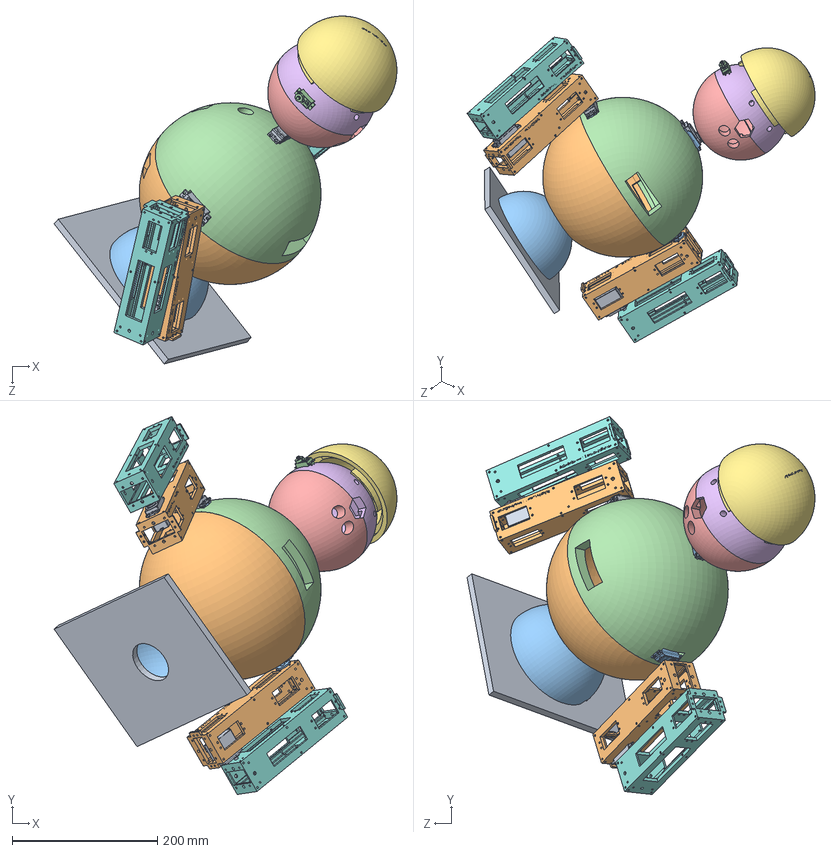
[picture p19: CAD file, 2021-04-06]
Mecanic/solidwork/robotinics.SLDASM
471.3 x 519.7 x 478.3 mm
BaseReta
BaseGrandeInf
BasePeqInf
BaseGrandeSup
cabecainf
cabecasup
chapeu
BRACO_BASE x 2
HS-475HB_001 x 4
BRACO_EXTENSAO x 2
HS5245MG x 3
MICRO SERVO 9g

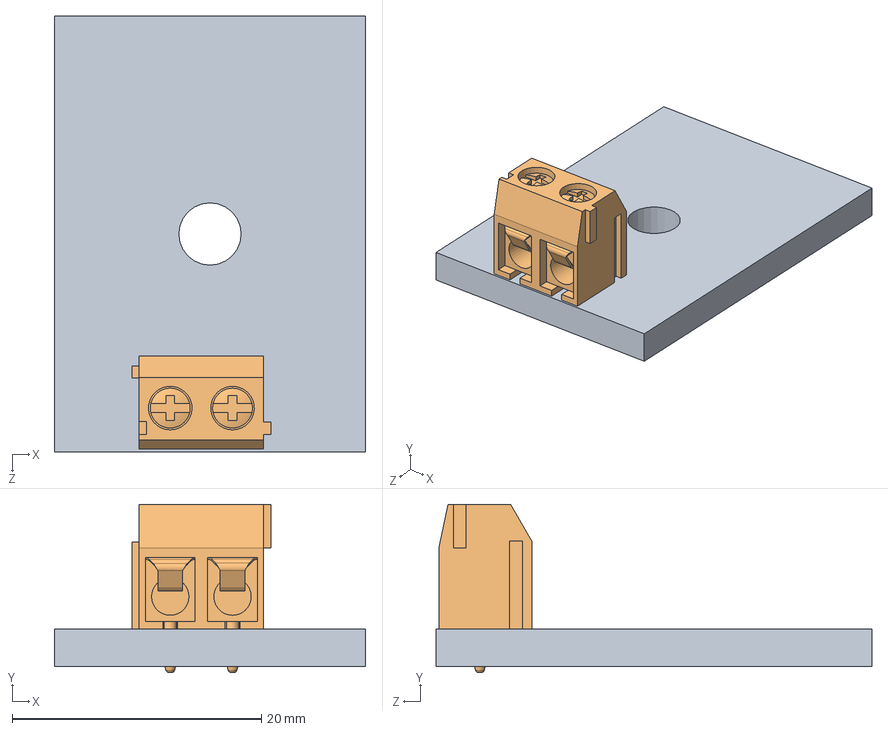
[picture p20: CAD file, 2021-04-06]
Mecanic/solidwork/Sensor Tensão.SLDASM
25.0 x 13.5 x 35.0 mm
Sensor Corrente
Borne

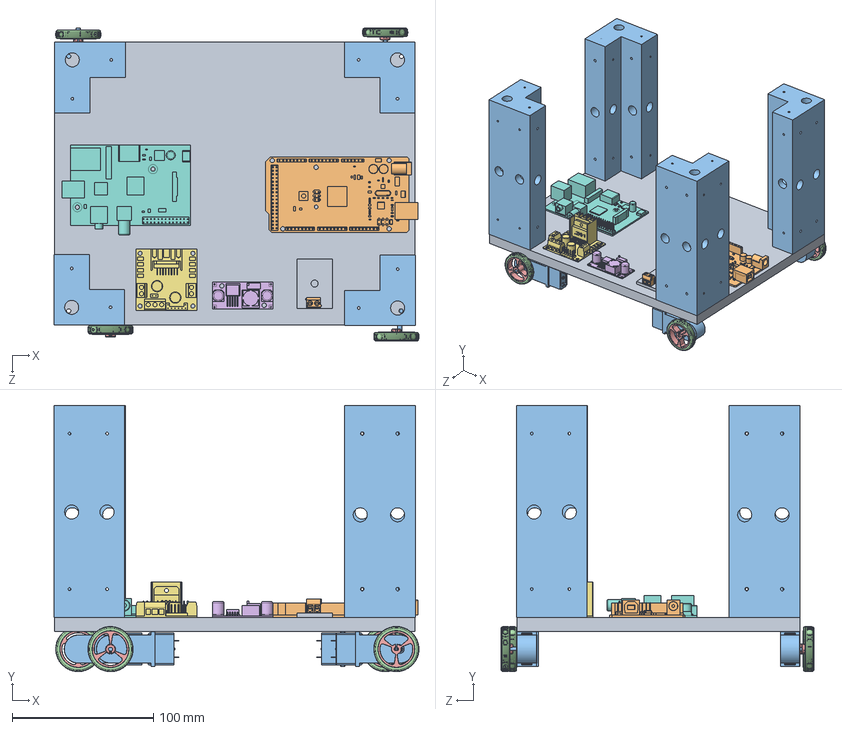
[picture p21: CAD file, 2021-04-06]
Mecanic/solidwork/Visão das Placas.SLDASM
258.1 x 188.4 x 221.6 mm
BaseRodas
ArduinoMega
Pololu Motor x 4
Pololu-Wheel-32x7mm-tire x 4
Pololu-Wheel-32x7mm-rim x 4
stepdown voltage converter
L298N
raspberry pi
Sensor Corrente
Borne
Prolongador x 4

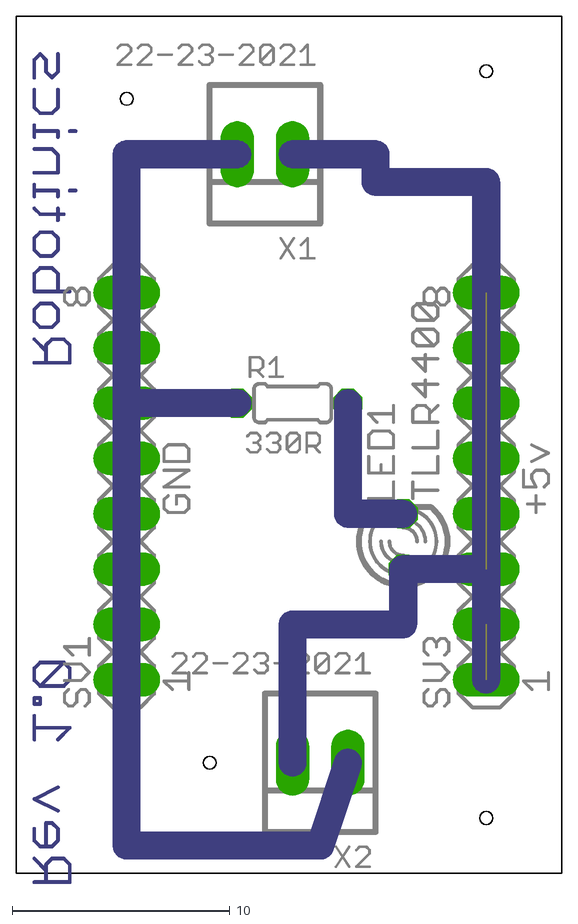
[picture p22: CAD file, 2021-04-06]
Eletronic/eagle/placa de distribuicao 5V/Placa distribuidora.dxf
25.1 x 39.8

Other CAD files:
Eletronic/eagle/Placa do Circuito do Carregador/placa do circuito do carregador.dxf
Mecanic/solidwork/brackets U/Channel Bracket.STEP
Mecanic/solidwork/CorpoSup.SLDPRT
Mecanic/solidwork/eletronica/placaled.dxf
Eletronic/eagle/Placa de Leds/placaled/placaled.SLDDRW
Eletronic/eagle/Placa de Leds/placaled/placaled.dxf
Mecanic/solidwork/BRACO_BASE.SLDPRT
Mecanic/solidwork/BRACO_BASE.STL
Mecanic/solidwork/BRACO_EXTENSAO.SLDDRW
Mecanic/solidwork/BRACO_EXTENSAO.SLDPRT
Mecanic/solidwork/BaseGrande.SLDPRT
Mecanic/solidwork/BaseGrande.STL
Mecanic/solidwork/BaseGrandeDAlto.SLDPRT
Mecanic/solidwork/BaseGrandeInf.SLDPRT
Mecanic/solidwork/BaseGrandeSup.SLDPRT
Mecanic/solidwork/BasePeqInf.SLDDRW
Mecanic/solidwork/BasePeqInf.SLDPRT
Mecanic/solidwork/BasePeqInf.STL
Mecanic/solidwork/BasePequena.SLDPRT
Mecanic/solidwork/BaseReta.SLDDRW
Mecanic/solidwork/BaseReta.SLDPRT
Mecanic/solidwork/BaseReta.STL
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

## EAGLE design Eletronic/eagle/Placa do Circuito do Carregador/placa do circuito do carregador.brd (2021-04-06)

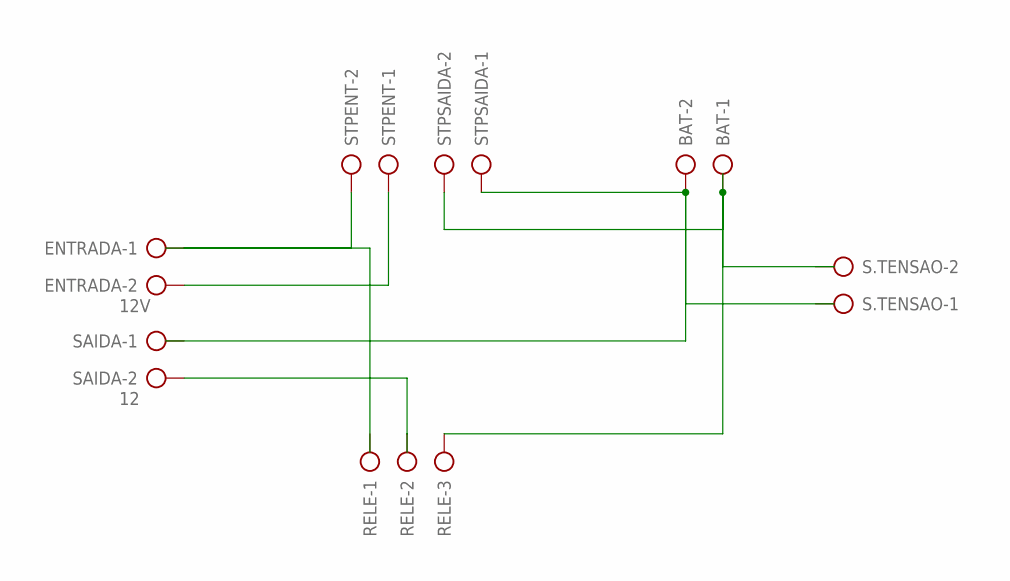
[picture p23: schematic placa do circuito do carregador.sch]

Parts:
BAT: AK300/2
ENTRADA: 12V; AK300/2
RELE: AK500/3-H
S.TENSAO: AK300/2
SAIDA: 12; AK300/2
STPENT: AK300/2
STPSAIDA: AK300/2

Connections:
unnamed: ENTRADA.1, STPENT.2
unnamed: BAT.2, STPSAIDA.1
unnamed: ENTRADA.2, STPENT.1
unnamed: BAT.1, RELE.3, STPSAIDA.2

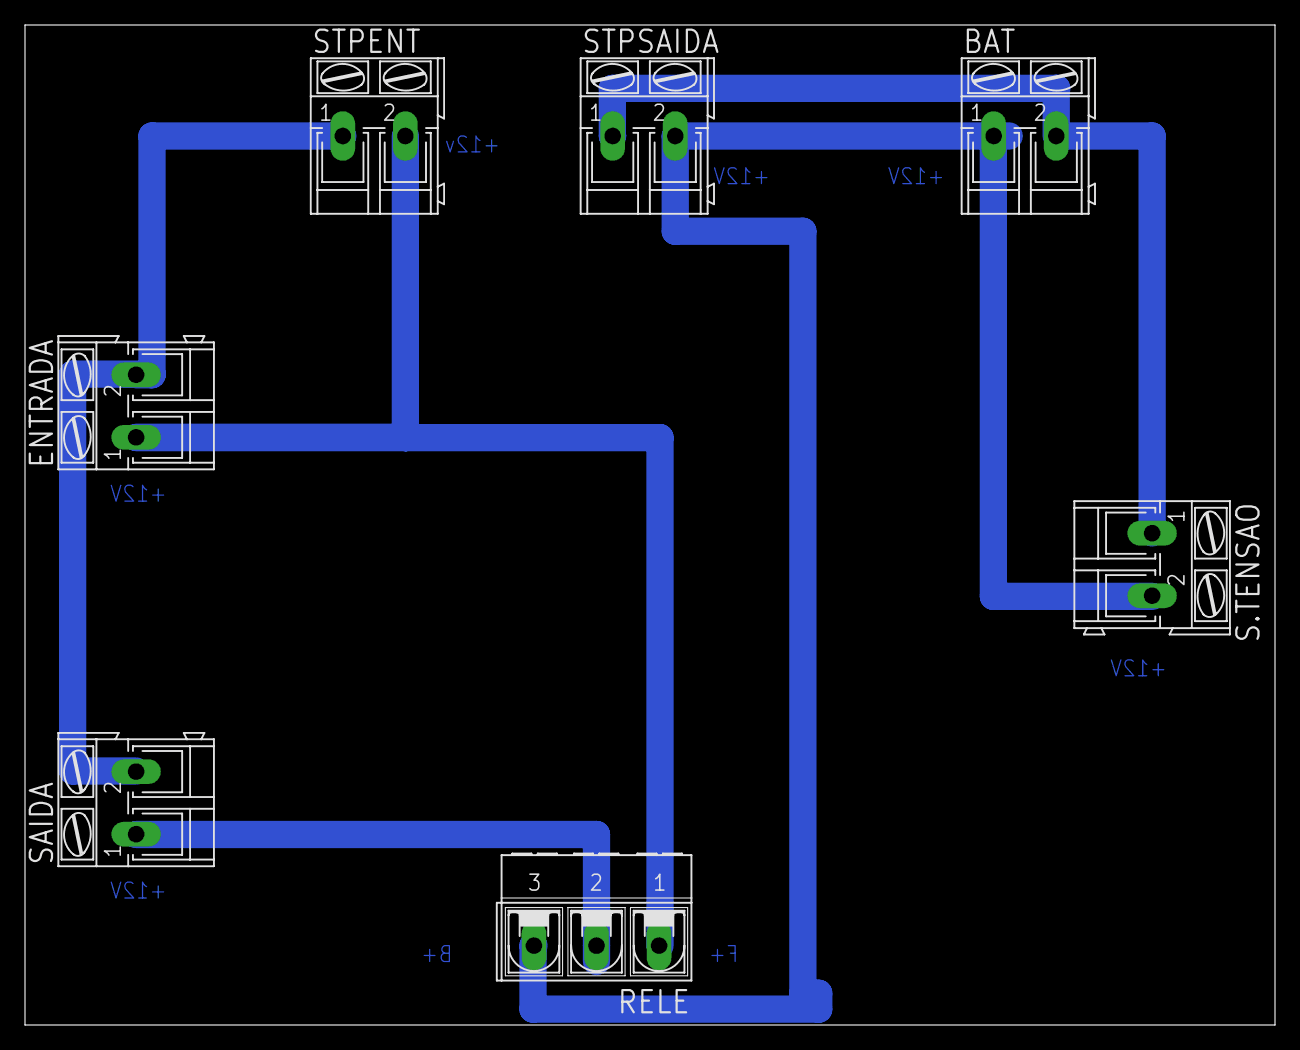
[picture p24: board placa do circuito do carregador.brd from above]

Board: 2 copper layers, 100.0 x 80.0 mm, 7 parts (0 on the bottom side), 4 nets.

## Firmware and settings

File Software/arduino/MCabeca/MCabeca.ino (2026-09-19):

/*
Criado por Marcelo Maurin Martins
Controle do segundo módulo do robotinics
Modulo Cabeca
22/11/2013
//Responsábilidade:
Gerenciar o laser e as luzes do robotinics

Comunicação diretamente com o arduino mega através de tx e rx ttl

*/
#include <SoftwareSerial.h>
#include <Servo.h>
#include <Ultrasonic.h>     //Carrega a biblioteca Ultrasonic

//SoftwareSerial mySerial(10, 11); // RX, TX - COMUNICAÇAO SERIAL ENTRE OS DOIS ARDUINOS
 //Este meio apesar de existir nao é utilizado
 //A comunicacao hoje é feita diretamente atravéz do raspberry

#define PINO_TRIGGER  13 //Define o pino do Arduino a ser utilizado com o pino Trigger do sensor
#define PINO_ECHO     2 //Define o pino do Arduino a ser utilizado com o pino Echo do sensor

Ultrasonic ultrasonic(PINO_TRIGGER, PINO_ECHO); //Inicializa o sensor ultrasonico

char FVersao[10] = "1.2";

//Partes 8 e 12
int pinCabecaX = 8;
int pinCabecaY = 12;
int pinLaser = 3; //ok
int pinOlhos = 7; //ok
int pinCLedAzul = 6; //ok
int pinCLedVerde = 9;
int pinCLedVermelho = 4; //ok
//int pinMov = 3;
//2,5,13??????
//int pinMovR = 13;

int pos = 0;    // variable to store the servo position 



int firstSensor = 0;    // first analog sensor
int secondSensor = 0;   // second analog sensor
int thirdSensor = 0;    // digital sensor
char inByte = 0;         // incoming serial byte

int contcor = 0;       //contador de cor da cabeca 
int contpasso = 0;
//faz variar a cor da cabeca funcao varialuz


Servo CabecaX;  // create servo object to control a servo 
Servo CabecaY;  // create servo object to control a servo 

String Buffer;

int cmCabeca;

void setup()
{
  Start_Serial();
  Start_Servo();
  Start_Olhos();
  Start_Cores();
  Start_Laser();
  Buffer = "";
  //TesteMovimento();

  //Serial.println("$>");
  Prompt();
}

void Prompt()
{
  //mySerial.println("$>");
  Serial.println("$>");
}
  


void Start_Cores()
{
   pinMode(pinCLedAzul, OUTPUT);  
   pinMode(pinCLedVerde, OUTPUT);  
   pinMode(pinCLedVermelho, OUTPUT);  

}

void Start_Olhos()
{
 pinMode(pinOlhos, OUTPUT);  
 
}

void Versao()
{
  Serial.println("ROBOTINICS Arduino Driver");
  Serial.println("Criado por Marcelo Maurin Martins");
  Serial.println("Robotinics Driver Cabeca");
  Serial.print("Versão");
  Serial.println(FVersao); 

}


void Start_Serial()
{
    // start serial port at 9600 bps:
  Serial.begin(57600);
  
  // set the data rate for the SoftwareSerial port
  //mySerial.begin(9600);
  Versao();
}



void Start_Laser()
{
  pinMode(pinLaser,OUTPUT);
 
  
}

void Start_Servo()
{
  CabecaX.attach(pinCabecaX);  // attaches the servo on pin 9 to the servo object  
  CabecaY.attach(pinCabecaY);  // attaches the servo on pin 9 to the servo object  
  CabecaX.write(90);
  CabecaY.write(0);
  

}

void LedCabecaAzul(bool flag)
{
   digitalWrite(pinCLedAzul,(flag==true)?HIGH:LOW );   
}

void LedCabecaVerde(bool flag)
{
   digitalWrite(pinCLedVerde,(flag==true)?HIGH:LOW );   
}

void LedCabecaVermelho(bool flag)
{
   digitalWrite(pinCLedVermelho,(flag==true)?HIGH:LOW );   
}

void LedOlhos(bool flag)
{
 digitalWrite(pinOlhos,(flag==true)?HIGH:LOW);  
}

void VariaLuz()
{
  contpasso++;
  if (contpasso > 200)
  {
     contcor++;
     if((contcor & 16)==1)
     {
         LedCabecaAzul(false);
         LedCabecaVerde(false);
         LedCabecaVermelho(false);
         LedOlhos(true);
     }
     else
     {
         LedOlhos(false);
         LedCabecaAzul((contcor & 2)?true:false);
         LedCabecaVerde((contcor & 4)?true:false);
         LedCabecaVermelho((contcor & 8)?true:false);

     }
     contpasso = 0;
  }

  
}


//Posiciona o laser na posicao
void Point(int y, int x)
{
      /*Serial.print("Posicionando x:");
      Serial.print(x);
      Serial.print(",");
      Serial.println(y);
      */
      CabecaY.write(y);
      CabecaX.write(x);
}

//Varre area com laser
void SCANNING()
{
  Serial.println("Iniciando Varredura");
  LaserON();
  for (int x=0;x<=180;x=x+5)
  {     
      Point(x,0);
      delay(400);
      Point(x,180);  
      delay(400); 
  }

  Point(90,0);
  LaserOFF();
}


void TesteMovimento()
{
   Serial.println("Iniciando teste de movimento");
   for(int cont=0;cont<=5;cont++)
   {
     //Olhos(not digitalRead(pinOlhos));
      LedOlhos(digitalRead(pinOlhos==HIGH));
     //digitalWrite(pinCLedAzul,HIGH ); 
     LedCabecaAzul(true);
      delay(150);
     //digitalWrite(pinCLedVerde,HIGH ); 
     LedCabecaVerde(true);
     delay(150);
     //digitalWrite(pinCLedVermelho,HIGH ); 
     LedCabecaVermelho(true);
     delay(150);
     delay(150);
     //digitalWrite(pinCLedAzul,HIGH ); 
     LedCabecaAzul(true);
     delay(150);
     //digitalWrite(pinCLedVerde,LOW ); 
     LedCabecaVerde(false);
     delay(150);
     //digitalWrite(pinCLedVermelho,HIGH ); 
     LedCabecaVermelho(true);
     delay(150);
     delay(150);
     //digitalWrite(pinCLedAzul,LOW ); 
     LedCabecaAzul(false);
     delay(150);
     //digitalWrite(pinCLedVerde,HIGH ); 
     LedCabecaVerde(true);
     delay(150);
     //digitalWrite(pinCLedVermelho,HIGH ); 
     LedCabecaVermelho(true);
     delay(150);
      delay(150);
     //digitalWrite(pinCLedAzul,HIGH); 
     LedCabecaAzul(true);
     delay(150);
     //digitalWrite(pinCLedVerde,HIGH ); 
     LedCabecaVerde(true);
     delay(150);
     //digitalWrite(pinCLedVermelho,LOW ); 
     LedCabecaVermelho(false);
     delay(150);
     //digitalWrite(pinCLedAzul,LOW ); 
     LedCabecaAzul(false);
     delay(150);
     //digitalWrite(pinCLedVerde,LOW ); 
     LedCabecaVerde(false);
     delay(150);
     //digitalWrite(pinCLedVermelho,LOW ); 
     LedCabecaVermelho(false);
     delay(150);
   }

  
  for(int cont=0;cont<=5;cont++)
 {
   //digitalWrite(pinOlhos,HIGH); 
   LedOlhos(true);
   delay(150);
   //digitalWrite(pinOlhos,LOW);
   LedOlhos(false);
   delay(150);
 }
  
  LaserON();
  //digitalWrite(pinLaser,HIGH);
  
  SCANNING();  //Varre area com laser
  LaserOFF();
  //digitalWrite(pinLaser,LOW);  
}





//Acende ou apaga a luz dos olhos
void Olhos(int Luz)
{
   digitalWrite(pinOlhos,Luz); 
}

void Le_Ultrasom(int Imprime)
{
  float cmMsec, inMsec;
  float cmMsec1, inMsec1;
  float cmMsec2, inMsec2;
  float cmMsec3, inMsec3;

  long microsec = ultrasonic.timing();  //Le os dados do sensor, com o tempo de retorno do sinal
  cmMsec1 = ultrasonic.convert(microsec, Ultrasonic::CM); //Calcula a distancia em centimetros
  inMsec1 = ultrasonic.convert(microsec, Ultrasonic::IN); //Calcula a distancia em polegadas
  
  microsec = ultrasonic.timing();  //Le os dados do sensor, com o tempo de retorno do sinal
  cmMsec2 = ultrasonic.convert(microsec, Ultrasonic::CM); //Calcula a distancia em centimetros
  inMsec2 = ultrasonic.convert(microsec, Ultrasonic::IN); //Calcula a distancia em polegadas  
  
   microsec = ultrasonic.timing();  //Le os dados do sensor, com o tempo de retorno do sinal
  cmMsec3 = ultrasonic.convert(microsec, Ultrasonic::CM); //Calcula a distancia em centimetros
  inMsec3 = ultrasonic.convert(microsec, Ultrasonic::IN); //Calcula a distancia em polegadas  
  
  microsec = ultrasonic.timing();  //Le os dados do sensor, com o tempo de retorno do sinal
  cmMsec = (cmMsec1 + cmMsec2 + cmMsec3) /3;
  inMsec = (inMsec1 + inMsec2 + inMsec3) /3;

  
  cmCabeca = cmMsec;
  if(Imprime==1)
  {
    Serial.print("Cent: ");
    Serial.print(cmMsec);
    Serial.print(", Pol. : ");
    Serial.println(inMsec); 
  }
  if(Imprime==2)
  {
    if(cmMsec<10)
    {
      Serial.print("Colisao eminente Cent: ");
      Serial.print(cmMsec);
      Serial.print(", Pol. : ");
      Serial.println(inMsec); 
      Prompt();
    }
  }
}


void ExecCMD(String pBuffer)
{
  Serial.print("Comando:");
  Serial.println(pBuffer);
  bool flgRum = false;
  if(pBuffer == "HEALTH")
  {
    Serial.println("MCAB:HEALTH:HEAD:OK");
    Serial.print("MCAB:POS:");
    Serial.print(CabecaX.read());
    Serial.print(",");
    Serial.println(CabecaY.read());
    flgRum = true;
  }

  if(pBuffer.indexOf("ULTRA")>=0)
  {
    //lcd.clear();
    Le_Ultrasom(1);
    flgRum = true;
    //Serial.print("ULTRA");
  }

  if(pBuffer.indexOf("MAN")>=0)
  {
    //lcd.clear();
    Help();
    flgRum = true;
    //Serial.println("CORR");
  }  

  //TesteMovimento
  if(pBuffer.indexOf("TESTE")>=0)
  {
    //lcd.clear();
    TesteMovimento();
    flgRum = true;
    //Serial.println("CORR");
  }  
  
  //Liga laser
  if(pBuffer.indexOf("LASERON")>=0)
  {
    //lcd.clear();
    //TesteMovimento();
    LaserON();
    flgRum = true;
    //Serial.println("CORR");
  }  
  
  //Liga laser
  if(pBuffer.indexOf("VER")>=0)
  {
    //lcd.clear();
    //TesteMovimento();
    Versao();
    flgRum = true;
    //Serial.println("CORR");
  }  

  
  if(pBuffer.indexOf("POINT:")>=0)
  {
    int virgula = pBuffer.indexOf(',');
    String sx = String(pBuffer.substring(7,virgula-1));
    String sy = String(pBuffer.substring(virgula+1));
    
    //Falta passar valor
    int x= 0;
    int y = 0;
    Point(x,y);
    
    flgRum = true;
    //Serial.print("MSG1:");
  }

  //Desliga laser
  if(pBuffer.indexOf("LASEROFF")>=0)
  {
    //lcd.clear();
    //TesteMovimento();
    LaserOFF();
    flgRum = true;
    //Serial.println("CORR");
  }  


  //Varre Area
  if(pBuffer.indexOf("SCANNING")>=0)
  {
    //lcd.clear();
    //TesteMovimento();
    SCANNING();
    flgRum = true;
    //Serial.println("CORR");
  }    
  
  if (flgRum==false)
  {
    Serial.println("Comando não reconhecido");
  }
  Prompt();
  //Serial.println("$>");
  Buffer = ""; 
}



void Help()
{
  Serial.println("MAN - Manual de comandos"); 
  Serial.println("ULTRA - Ultrasom"); 
  Serial.println("VER - Versao do MCabeca");
  Serial.println("LASERON - Liga laser");
  Serial.println("LASEROFF - Desliga laser");
  Serial.println("SCANNING - Varre area com laser");
  Serial.println("POINT - Aponta laser posicao POINT=x,y");
  Serial.println("TESTE - Teste de Movimento"); 
  Serial.println("HEALTH - Estado estruturado do modulo"); 

}


/*
void Le_Arduino()
{
  // if we get a valid byte, read analog ins:
  if (mySerial.available() > 0) {
    // get incoming byte:
    inByte = mySerial.read();
    if (inByte != '\n')
    {
      Buffer += inByte;
    }
    else
    {
      ExecCMD(Buffer);
      //mySerial.println("$>");
      Prompt();
      Buffer = ""; 
    }

  }
}
*/

//Realiza Leituras de dispositivos
void Leituras()
{
  Le_Ultrasom(2);
  Serial_Read();
  //Le_Arduino();
  //Le_gas();
  //Le_corr();
  
}

void LaserON()
{
  digitalWrite(pinLaser,HIGH);
}

void LaserOFF()
{
 digitalWrite(pinLaser,LOW); 
}

void loop()
{
  Leituras();
  VariaLuz();
 
}




void Serial_Read()
{  
 // if we get a valid byte, read analog ins:
  if (Serial.available() > 0) {
    // get incoming byte:
    inByte = Serial.read();
    if (inByte != '\n')
    {
      Buffer = Buffer + inByte;
      //sprintf(Buffer,"%s%c",Buffer,inByte);
      //Serial.print(Buffer);
    }
    else
    {
      ExecCMD(Buffer);

    }
  }
  
}

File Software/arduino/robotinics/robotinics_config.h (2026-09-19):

#ifndef ROBOTINICS_CONFIG_H
#define ROBOTINICS_CONFIG_H

#include <Arduino.h>

/*
  Robotinics Rev. 4 - configuracao do Body Controller (Arduino Mega)

  IMPORTANTE:
  - os valores abaixo preservam a pinagem do firmware legado v1.3;
  - alteracoes de pinagem exigem revisao da documentacao e validacao fisica;
  - baud rates fazem parte do contrato de compatibilidade.
*/

#define ROBOTINICS_FIRMWARE_VERSION "1.3"

// Interfaces
static const unsigned long ROBOTINICS_USB_BAUD = 115200;
static const unsigned long ROBOTINICS_BLUETOOTH_BAUD = 9600;
static const unsigned long ROBOTINICS_HEAD_BAUD = 9600;
static const unsigned long ROBOTINICS_GPS_BAUD = 4800;

// Servos / corpo
static const uint8_t pinCabeca    = 6;
static const uint8_t pinBDireito  = 44;
static const uint8_t pinMDireita  = 8;
static const uint8_t pinBEsquerdo = 9;
static const uint8_t pinGARRAESQ  = 10;
static const uint8_t pinGARRADIR  = 11;
static const uint8_t pinPEsquerdo = 46;

// Entradas analogicas
static const uint8_t pinVoltagem = A6;
static const uint8_t pinacelx = A1;
static const uint8_t pinacely = A2;
static const uint8_t pinacelz = A3;
static const uint8_t analogInGas = A4;
static const uint8_t analogOutGas = A5;
static const uint8_t analogInCorr = A0;

// Ponte H / tracao
static const uint8_t PINO_ENA = 26;
static const uint8_t PINO_IN1 = 28;
static const uint8_t PINO_IN2 = 30;
static const uint8_t PINO_IN3 = 34;
static const uint8_t PINO_IN4 = 32;
static const uint8_t PINO_ENB = 36;

// RF
static const uint8_t PINO_RFRX = 17;
static const uint8_t PINO_RFTX = 16;

// Ultrassom
static const uint8_t PINO_TRIGGER  = 2;
static const uint8_t PINO_ECHO     = 3;
static const uint8_t PINO_TRIGGER1 = 40;
static const uint8_t PINO_ECHO1    = 35;
static const uint8_t PINO_TRIGGER2 = 41;
static const uint8_t PINO_ECHO2    = 42;

// Comunicacao com controlador secundario / MCabeca.
// Nomes historicos preservados; a documentacao de pinout explica a semantica.
static const uint8_t Arduino2TX = 38;
static const uint8_t Arduino2RX = 37;

// Seguranca
static const int ROBOTINICS_COLLISION_MARGIN_CM = 20;

// Timeout deterministico de tracao.
// Qualquer comando FRENTE/RE/GESQ/GDIR precisa ser renovado antes deste prazo
// para manter o movimento continuo.
static const unsigned long ROBOTINICS_MOTION_TIMEOUT_MS = 30000UL;

// Watchdog de atividade do controlador externo enquanto ha tracao ativa.
// Protege contra perda do Raspberry, USB ou cliente Bluetooth.
static const unsigned long ROBOTINICS_CONTROL_WATCHDOG_MS = 3000UL;

// Permite desligar temporariamente os timeouts em bancada sem alterar o codigo.
static const bool ROBOTINICS_SAFETY_TIMEOUTS_ENABLED = true;

#endif

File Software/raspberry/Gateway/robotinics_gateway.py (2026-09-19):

#!/usr/bin/env python3
import json
import logging
import os
import queue
import signal
from http.server import BaseHTTPRequestHandler, ThreadingHTTPServer
import sys
import threading
import time
import uuid
from collections import deque
from pathlib import Path

import serial

LOG = logging.getLogger("robotinics-gateway")
RUN = threading.Event()
RUN.set()

PORT = os.getenv("ROBOTINICS_SERIAL_PORT", "/dev/ttyACM0")
BAUD = int(os.getenv("ROBOTINICS_SERIAL_BAUD", "115200"))
STATE_DIR = Path(os.getenv("ROBOTINICS_STATE_PATH", "/var/lib/robotinics"))
STATE_FILE = STATE_DIR / "gateway-state.json"
HISTORY_FILE = STATE_DIR / "gateway-history.jsonl"
MAINTENANCE_DIR = STATE_DIR / "maintenance-reports"
LISTEN_HOST = os.getenv("ROBOTINICS_GATEWAY_HOST", "127.0.0.1")
LISTEN_PORT = int(os.getenv("ROBOTINICS_GATEWAY_PORT", "8765"))
DEFAULT_TIMEOUT = float(os.getenv("ROBOTINICS_COMMAND_TIMEOUT", "5"))
DEFAULT_RETRIES = int(os.getenv("ROBOTINICS_COMMAND_RETRIES", "1"))
HISTORY_SIZE = int(os.getenv("ROBOTINICS_HISTORY_SIZE", "200"))
EVENT_SIZE = int(os.getenv("ROBOTINICS_EVENT_SIZE", "200"))
HEARTBEAT_INTERVAL = float(os.getenv("ROBOTINICS_HEARTBEAT_INTERVAL", "1.0"))
HEARTBEAT_TIMEOUT = float(os.getenv("ROBOTINICS_HEARTBEAT_TIMEOUT", "2.0"))

CONNECTION_DISCONNECTED = "DISCONNECTED"
CONNECTION_CONNECTING = "CONNECTING"
CONNECTION_CONNECTED = "CONNECTED"
CONNECTION_DEGRADED = "DEGRADED"

PRIORITY_EMERGENCY = 0
PRIORITY_HIGH = 10
PRIORITY_NORMAL = 50
PRIORITY_LOW = 90

MOTION_COMMANDS = {"FRENTE", "RE", "GESQ", "GDIR"}
RETRY_SAFE_COMMANDS = {
    "PING", "SAFETY", "IDENTIFY", "CAPABILITIES", "HEALTH", "ULTRA", "ULTRA1",
    "ULTRA2", "GAS", "CORR", "GPS", "ACEL", "VER"
}

ANGLE_PREFIXES = (
    "GCABECAESQ=", "GPPUNHOESQ=", "GPPUNHODIR=", "GCABECADIR=",
    "GBDIR=", "GBESQ=", "GPGARRADIR=", "GPGARRAESQ="
)
EXACT_COMMANDS = {
    "RE", "PARA", "FRENTE", "GESQ", "GDIR", "CLS", "GPS", "ACEL",
    "ULTRA", "ULTRA1", "ULTRA2", "GAS", "CORR", "MAN", "VER", "TESTE",
    "LCDCLEAR", "PING", "SAFETY", "IDENTIFY", "CAPABILITIES", "HEALTH"
}
MCAB_EXACT = {
    "DIST", "GETPOS", "CENTER", "LASERON", "LASEROFF", "SCANNING",
    "VER", "MAN", "ULTRA", "TESTE", "HEALTH"
}
MCAB_BOOL_PREFIXES = (
    "LEDAZUL=", "LEDVERDE=", "LEDVERMELHO=", "OLHOS=", "LIGHTAUTO="
)


def _priority_for(command, internal=False):
    if command == "PARA":
        return PRIORITY_EMERGENCY
    if internal and command == "PING":
        return PRIORITY_LOW
    if command in {"SAFETY", "IDENTIFY", "CAPABILITIES"}:
        return PRIORITY_HIGH
    return PRIORITY_NORMAL


class RobotState:
    def __init__(self):
        self.lock = threading.RLock()
        self.data = {
            "connected": False,
            "connection": {
                "state": CONNECTION_DISCONNECTED,
                "since": time.time(),
                "last_change_reason": "startup",
            },
            "serial_port": PORT,
            "serial_baud": BAUD,
            "last_seen": None,
            "last_line": None,
            "active_request_id": None,
            "device": None,
            "capabilities": [],
            "head": {
                "x": None,
                "y": None,
                "distance_cm": None,
                "laser": None,
                "led_blue": None,
                "led_green": None,
                "led_red": None,
                "eyes": None,
                "light_auto": None,
            },
            "sensors": {
                "ultra_cm": None,
                "ultra1_cm": None,
                "ultra2_cm": None,
                "gas": None,
                "current": None,
            },
            "motion": {
                "last_command": None,
                "stopped": None,
                "safety_stop_reason": None,
                "last_heartbeat": None,
            },
            "health": {
                "body": "UNKNOWN",
                "head": "UNKNOWN",
                "safety": "UNKNOWN",
                "motion": "UNKNOWN",
                "updated_at": None,
            },
            "telemetry": {},
            "faults": [],
            "last_error": None,
        }

    def set_connection(self, state, reason=None):
        with self.lock:
            current = self.data["connection"]["state"]
            if current != state:
                self.data["connection"] = {
                    "state": state,
                    "since": time.time(),
                    "last_change_reason": reason,
                }
            elif reason is not None:
                self.data["connection"]["last_change_reason"] = reason
            self.data["connected"] = state == CONNECTION_CONNECTED
            self._save()

    def update(self, **kwargs):
        with self.lock:
            self.data.update(kwargs)
            self._save()

    def parse_line(self, line, active_command=None):
        now = time.time()
        with self.lock:
            self.data["last_seen"] = now
            self.data["last_line"] = line
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

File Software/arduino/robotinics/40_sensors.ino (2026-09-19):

// Sensores ----------------------------------------------------------------

void Start_acel()
{
  xLastValue = analogRead(pinacelx);
  yLastValue = analogRead(pinacely);
  zLastValue = analogRead(pinacelz);
}

void Carrega_acel()
{
  xValue = analogRead(pinacelx);
  yValue = analogRead(pinacely);
  zValue = analogRead(pinacelz);

  xAcel = xValue - xLastValue;
  yAcel = yValue - yLastValue;
  zAcel = zValue - zLastValue;
}

void Le_ace()
{
  Print("acel:");
  Print(String(xValue));
  Print(",");
  Print(String(yValue));
  Print(",");
  Print(String(zValue));
}

void StartGas()
{
  // Mantido conforme hardware original.
  pinMode(analogOutGas, INPUT);
}

void Carrega_gas()
{
  const int sensorValue1 = analogRead(analogInGas);
  const int sensorValue2 = analogRead(analogInGas);
  const int sensorValue3 = analogRead(analogInGas);
  const int sensorValue = (sensorValue1 + sensorValue2 + sensorValue3) / 3;

  if (sensorValue <= 0) {
    thickness = -20000;
    return;
  }

  thickness = 20000 - (5000 * (1023 / (float)sensorValue) - 1);
}

void Le_gas()
{
  if (thickness < -10812) Println("Nao detectado sensor fumaça");
  else if (thickness < -3462) Println("Indicio sensor fumaça");
  else if (thickness < 1990) Println("Detectado sensor fumaça");
  else Println("Forte sinal sensor fumaça");
}

void Carrega_corr()
{
  const int sensorValue = analogRead(analogInCorr);
  Corrente = map(sensorValue, 0, 1023, -30, 30);
}

void Le_corr()
{
  Carrega_corr();
  Print("Corrente:");
  dtostrf(Corrente, 0, 2, sInfo);
  Println(String(sInfo));
}

static float leituraUltrassomCM(Ultrasonic &sensor, long &microsec)
{
  microsec = sensor.timing();
  return sensor.convert(microsec, Ultrasonic::CM);
}

void Le_Ultrasom(int Imprime)
{
  long microsec = 0;
  const float cmMsec = leituraUltrassomCM(ultrasonic, microsec);
  const float inMsec = ultrasonic.convert(microsec, Ultrasonic::IN);

  cmRe = (int)cmMsec;

  if (Imprime != 0) {
    Print("Cent: ");
    dtostrf(cmMsec, 0, 2, sInfo);
    Print(String(sInfo));
    Print(", Pol. : ");
    dtostrf(inMsec, 0, 2, sInfo);
    Println(String(sInfo));
  }
}

void Le_Ultrasom1(int Imprime)
{
  long microsec = 0;
  const float cmMsec = leituraUltrassomCM(ultrasonic1, microsec);
  const float inMsec = ultrasonic1.convert(microsec, Ultrasonic::IN);

  cmCorpo = (int)cmMsec;

  if (Imprime != 0) {
    Print("Cent: ");
    dtostrf(cmMsec, 0, 2, sInfo);
    Print(String(sInfo));
    Print(", Pol. : ");
    dtostrf(inMsec, 0, 2, sInfo);
    Println(String(sInfo));
  }
}

void Le_Ultrasom2(int Imprime)
{
  long microsec = 0;
  const float cmMsec = leituraUltrassomCM(ultrasonic2, microsec);
  const float inMsec = ultrasonic2.convert(microsec, Ultrasonic::IN);

  // Mantem leitura independente do sensor da cabeca.
  cmCabeca = (int)cmMsec;

  if (Imprime != 0) {
    Print("Cent: ");
    dtostrf(cmMsec, 0, 2, sInfo);
    Print(String(sInfo));
    Print(", Pol. : ");
    dtostrf(inMsec, 0, 2, sInfo);
    Println(String(sInfo));
  }
}

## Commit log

2021-04-06 projeto robotinics
    [1499.SLDASM, BRACO_BASE.SLDPRT, BRACO_BASE.STL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]
2026-08-12 Adiciona livro Robotinics Rev. 3 com integração de IA
2026-09-18 docs: registra origem do Robotinics como TCC de 2015
2026-09-18 docs(ai): adiciona continuidade com Raspberry Pi e TCHATGPT
    * docs(ai): adiciona guias base para IA e agentes
    * docs(ai): adiciona guias base para IA e agentes
    * docs(ai): adiciona guias base para IA e agentes
    * docs(ai): adiciona guias base para IA e agentes
    * docs(ai): adiciona guias base para IA e agentes
    * docs(ai): detalha arquitetura internet runtime e manutencao documental
    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
2026-09-18 feat(yocto): adiciona imagem Raspberry Pi com meta-robotinics
    * feat(yocto): cria base Wrynose para Raspberry Pi
    * feat(yocto): cria base Wrynose para Raspberry Pi
    * feat(yocto): cria base Wrynose para Raspberry Pi
    * feat(yocto): cria base Wrynose para Raspberry Pi
    * feat(yocto): cria base Wrynose para Raspberry Pi
    * feat(yocto): adiciona configuracao gateway IA e voz
    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
    [robotinics-rpi4.yml, robotinics-rpi5.yml]
2026-09-18 refactor(yocto): move imagem para Software/raspberry
    * refactor(yocto): move imagem para Software/raspberry
    * docs: corrige links Yocto para pasta do Raspberry
    * docs: fixes Yocto link under Raspberry
    * docs: corrige enlace Yocto bajo Raspberry
    * docs(raspberry): integra Yocto como submodulo
    * docs(raspberry): documents local Yocto image
    * docs(raspberry): documenta imagen Yocto local
    * docs(yocto): ajusta navegacao apos mover para Raspberry
    * docs(yocto): fixes navigation after Raspberry move
    * docs(yocto): corrige navegacion despues del cambio
    [robotinics-rpi4.yml, robotinics-rpi5.yml]
2026-09-18 feat(voice): substitui eSpeak por TTS Lazarus com TCHATGPT
    * feat(voice): adiciona TTS Lazarus via TCHATGPT
    * feat(voice): adiciona TTS Lazarus via TCHATGPT
    * feat(voice): adiciona TTS Lazarus via TCHATGPT
    * feat(voice): adiciona TTS Lazarus via TCHATGPT
    * feat(voice): adiciona TTS Lazarus via TCHATGPT
    * feat(voice): adiciona TTS Lazarus via TCHATGPT
    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
    [robotinics-rpi4.yml, robotinics-rpi5.yml]
2026-09-18 feat(yocto): adiciona cross-compile ARM64 do Robotinics Voice
    * feat(yocto): adiciona fontes headless TCHATGPT para voz ARM64
    * feat(yocto): adiciona fontes headless TCHATGPT para voz ARM64
    * feat(yocto): adiciona fontes headless TCHATGPT para voz ARM64
    * feat(yocto): adiciona fontes headless TCHATGPT para voz ARM64
    * feat(yocto): adiciona cross-compile FPC ARM64 para voz
    * feat(yocto): adiciona cross-compile FPC ARM64 para voz
    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
    [robotinics-rpi4.yml, robotinics-rpi5.yml]
2026-09-18 feat(raspberry): implementa gateway e runtime TCHATGPT
    * feat(gateway): adiciona fila comandos estado validacao e API local
    * feat(gateway): expõe API HTTP JSON local
    * feat(raspberry): adiciona cliente gateway tarefas docs e internet
    * feat(raspberry): adiciona cliente gateway tarefas docs e internet
    * feat(raspberry): adiciona cliente gateway tarefas docs e internet
    * feat(raspberry): adiciona cliente gateway tarefas docs e internet
    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
    [robotinics-rpi4.yml, robotinics-rpi5.yml]
2026-09-18 feat(ai): completa contexto do runtime Raspberry
2026-09-19 docs(rev4): define política de compatibilidade
2026-09-19 fix(mega): inicializa receptor RF no setup
    [robotinics.ino]
2026-09-19 feat(safety): configura timeouts de movimento e controle
2026-09-19 feat(safety): adiciona watchdog e timeout de tracao
2026-09-19 feat(safety): define lease de controle e limite de movimento
2026-09-19 feat(gateway): envia heartbeat de seguranca durante movimento
2026-09-19 docs(mega): documenta watchdog e timeout de movimento
2026-09-19 refactor(safety): move tipos publicos para header
2026-09-19 docs(ci): registra compilacao verde de Mega e MCabeca
2026-09-19 test(protocol): adiciona testes do Device Protocol
2026-09-19 docs(protocol): formaliza Device Protocol 1.x
2026-09-19 test(simulator): cobre protocolo sensores e safety
2026-09-19 fix(simulator): corrige caminhos do teste de integracao
2026-09-19 feat(simulator): implementa MCAB HEALTH para autoteste
2026-09-19 test(maintenance): cobre persistencia e indice de relatorios
2026-09-19 docs(rev4): conclui autoteste e relatorio de manutencao
2026-09-19 fix(telemetry): adiciona estado independente do ultrassom da cabeca
    [robotinics.ino]
2026-09-19 fix(telemetry): separa leitura do sensor ultrassom da cabeca
    [40_sensors.ino]
2026-09-19 fix(taskengine): evita colisao de identificador no FPC 3.2.2
2026-09-19 feat(agent): adiciona ferramentas tipadas e politica de acoes
2026-09-19 feat(agent): integra catalogo de ferramentas e confirmacao ao prompt
2026-09-19 test(agent): cobre politica de confirmacao e bloqueio
2026-09-19 ci: valida RAG e politica de acoes em Free Pascal
2026-09-19 docs(agent): documenta RAG ranking e politica de ferramentas
2026-09-19 fix(rag): torna contagem de palavras compativel com FPC 3.2.2
2026-09-19 feat(agent): adiciona executor de ferramentas governado por policy
2026-09-19 ci: valida RAG hibrido e executor de ferramentas
2026-09-19 feat(agent): adiciona modo CLI auditavel para executar ferramentas
2026-09-19 ci: instala unidades de rede do Free Pascal
2026-09-19 test(rag): valida FTS5 incremental e remocao de documentos

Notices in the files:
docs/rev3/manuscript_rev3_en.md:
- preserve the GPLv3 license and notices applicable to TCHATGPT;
